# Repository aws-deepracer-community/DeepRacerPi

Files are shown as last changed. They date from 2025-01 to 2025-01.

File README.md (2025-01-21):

# Introducing the DeepRacer Pi: A Budget-Friendly Compute Module Replacement for AWS DeepRacer

The **DeepRacer Pi** is a custom-designed PCB that serves as a cost-effective replacement for the original AWS DeepRacer compute module. With a production and assembly cost of just **$33**, the DeepRacer Pi brings the power of the **Raspberry Pi Compute Module 4 (CM4)** and the upcoming **Compute Module 5 (CM5)** to your DIY racing projects.

PiRacer PCB

## What You Need
To get started with the DeepRacer Pi, you’ll need:
1. **Raspberry Pi CM4 Lite**: 
2. **SD Card**: 
3. **PiCamera V2**:

---

The DeepRacer Pi empowers makers and students to build, modify, and innovate with their AWS DeepRacer cars. it is a small enough package to fit into 1/28th scale car significantly reducing the footprint needed for AWS DeepRacer.

## TODO for DeepRacer Pi Development
1. **Move Camera and unneeded headers**
   - remove the extra header not needed for the servo control
   - move the camera next to the headers to face forward

2. **Implement Battery Monitor**  
   - Add circuitry and software support to monitor battery voltage and health.
   - Display battery status in real-time for improved usability.

3. **Fix USB OTG Support**  
   - Modify USB configuration to enable OTG (On-The-Go) functionality.
   - Ensure compatibility with peripherals and reliable data transfer.
4. **Add Tail light LED**
   - Implement multicolor Tail light indicator
5. **Add Fan header**
   - Enable FAN for additional cooling support
6. **Add UART via serial connector headers**
   - to enable additional debugging

## Setting Up the board

1. **Image SD card with  Ubuntu 22.04**
   - use win+shift+x to enable SSH and Wifi during imaging process
   - Edit /boot/firmware/config.txt
     - Add dtparam=i2c_arm=on
     - Add Start_x=1
     - Add dtoverlay=vc4-fkms-v3d
2. Follow these instructions
   - https://github.com/aws-deepracer-community/deepracer-custom-car

Special Thanks for Lars for all the work he did on the Deepracer-custom-car repo to make this a possibility!

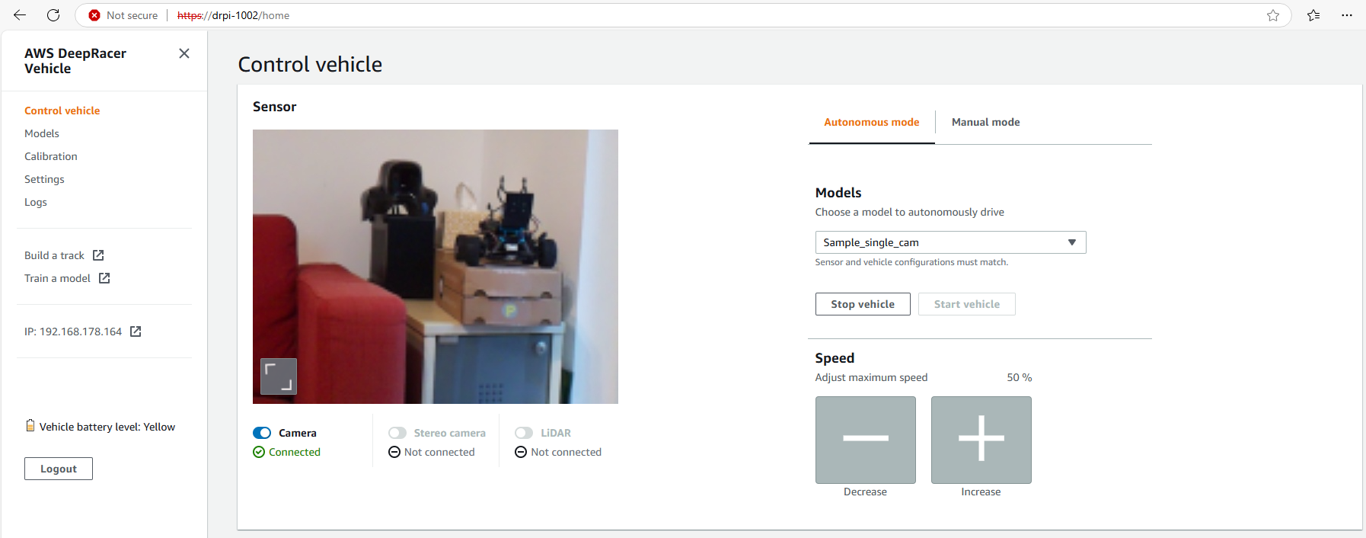
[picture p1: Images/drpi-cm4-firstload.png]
PiRacer PCB


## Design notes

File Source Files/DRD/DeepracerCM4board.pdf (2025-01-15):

Carrier board for CM4

Servo Controller

Power supply: 5V (Pi connector) OR 6V~12V (VIN terminal) - JST-XH 3-pin connection

Servo voltage: 5V

Logic voltage: 3.3V

Driver: PCA9685

Control interface: I2C

Camera connection

SD card Connection

USB Port

USB-C additional power input along with the battery.

Battery gauge

Hirose connector for the CM4 board.

The implementation of the PCA9685 should mimic the waveshare hat for the raspberry pi 4 found here:

https://www.waveshare.com/product/raspberry-pi/hats/motors-relays/servo-driver-hat.htm

1

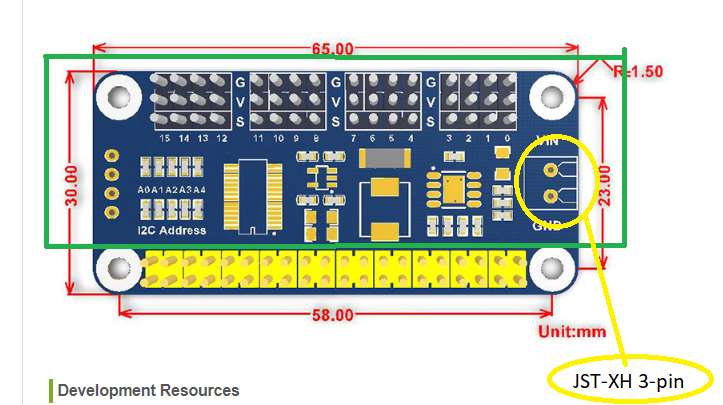
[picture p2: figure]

Data sheet: https://www.waveshare.com/wiki/Servo_Driver_HAT
Schematic: https://files.waveshare.com/upload/a/a2/Servo_Driver_HAT_Schematic_.pdf

I do not want all the connections that exist on the board below. the below board is linked for roughly footprint size I am looking,
Similar to the board size and orientation I am looking for however, I would need mount holes so a little sider is ok. https://www.waveshare.com/product/raspberry-pi/boards-kits/computemodule-4-cat/cm4-nano-c.htm?___SID=U

datasheet: https://www.waveshare.com/wiki/CM4-NANO-C
schematic: https://files.waveshare.com/upload/d/de/CM4-NANO-C-SCH.pdf

2

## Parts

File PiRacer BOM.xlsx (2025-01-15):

Id | Footprint | Quantity | Designators | Designation | Digikey Link
1 | RES_0816_SUS | 2 | R2, R6 | RG1608P-512-B-T5 | https://www.digikey.com/en/products/detail/susumu/RG1608P-512-B-T5/1240605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
2 | MOLEX_1054500101 | 1 | J7 | 1054500101 | https://www.digikey.com/en/products/detail/molex/1054500101/5843890
3 | IND_TAIYO_NR8040_TAY | 1 | L2 | NR8040T3R6N | https://www.digikey.com/en/products/detail/taiyo-yuden/NR8040T3R6N/1739080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
4 | 805 | 1 | R4 | RC0805FR-07115KL | https://www.digikey.com/en/products/detail/yageo/RC0805FR-07115KL/727564
5 | 1206 | 1 | R12 | RC1206FR-0722K1L | https://www.digikey.com/en/products/detail/yageo/RC1206FR-0722K1L/728690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
6 | TSOT-23-5 | 1 | IC1 | RT9742GGJ5 | https://www.digikey.com/en/products/detail/richtek-usa-inc/RT9742GGJ5/5880519
7 | RC0402N_YAG | 6 | R1, R15, R16, R21, R22, R23 | RC0402JR-0710KL | https://www.digikey.com/en/products/detail/yageo/RC0402JR-0710KL/726418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
8 | SO-8EP_DIO | 1 | U5 | AP64501SP-13 | https://www.digikey.com/en/products/detail/diodes-incorporated/AP64501SP-13/10419715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
11 | RESC2012X60N | 1 | R3 | RMCF0805FT15K8 (https://www.digikey.com/en/products/detail/stackpole-electronics-inc/RMCF0805FT15K8/1712710) | https://www.digikey.com/en/products/detail/stackpole-electronics-inc/RMCF0805FT15K8/1712710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
12 | RC0805N_YAG | 1 | C12 | CGA4J2X7R2A104K125AA | https://www.digikey.com/en/products/detail/tdk-corporation/CGA4J2X7R2A104K125AA/2443305
13 | CAPC3225X270N | 3 | C8, C9, C11 | TMK325B7226MMHP | https://www.digikey.com/en/products/detail/taiyo-yuden/TMK325B7226MMHP/10473818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
14 | CAPC1608X90 | 1 | C6 | CC0603KRX7R9BB272 | https://www.digikey.com/en/products/detail/yageo/CC0603KRX7R9BB272/5195216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
16 | CAPC1608X90 | 1 | C4 | 0603B102K500SD | https://www.digikey.com/en/products/detail/nextgen-components/0603B102K500SD/15761330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
17 | CAP_CL31_SAM | 1 | C3 | CL31A106MAHNNNE | https://www.digikey.com/en/products/detail/samsung-electro-mechanics/CL31A106MAHNNNE/3886839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
18 | CONN_61300411121_WRE | 4 | J4, J10, J11, J12 | 61300411121 | https://www.digikey.com/en/products/detail/w%C3%BCrth-elektronik/61300411121/4846827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
19 | SOT361-1_NXP-M | 1 | U2 | PCA9685PW,112 | https://www.digikey.com/en/products/detail/nxp-usa-inc/PCA9685PW-112/2034324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
20 | TSW-104-07-G-D_SAI | 4 | J3, J5, J8, J9 | TSW-104-07-F-D | https://www.digikey.com/en/products/detail/samtec-inc/TSW-104-07-F-D/2685891
21 | CAP_GRM21_2p15X1p4X1p4_MUR | 1 | C21 | GRM21BR71A106KA73L | https://www.digikey.com/en/products/detail/murata-electronics/GRM21BR71A106KA73L/5027600
22 | Raspberry-Pi-4-Compute-Module | 2 | Module1A, Module1B | DF40C-100DS-0.4V | https://www.digikey.com/en/products/detail/hirose-electric-co-ltd/DF40C-100DS-0-4V-51/1969476
23 | JST_B3B-XH-A | 1 | J2 | B3B-XH-A | https://www.digikey.com/en/products/detail/jst-sales-america-inc/B3B-XH-A/1651046
24 | CON15_1X15_DRB_SFW_FCI | 1 | J1 | SFW15R-1STAE1LF | https://www.digikey.com/en/products/detail/amphenol-cs-fci/SFW15R-1STAE1LF/4270877
25 | SDCARD_MOLEX_503398-1892 | 1 | J6 | 5033981892 | https://www.digikey.com/en/products/detail/molex/5033981892/4555393
15 | CAP_CC0805_YAG-L | 1 | C5 | CC0805ZRY5V7BB104 | https://www.digikey.com/en/products/detail/yageo/CC0805ZRY5V7BB104/5884304

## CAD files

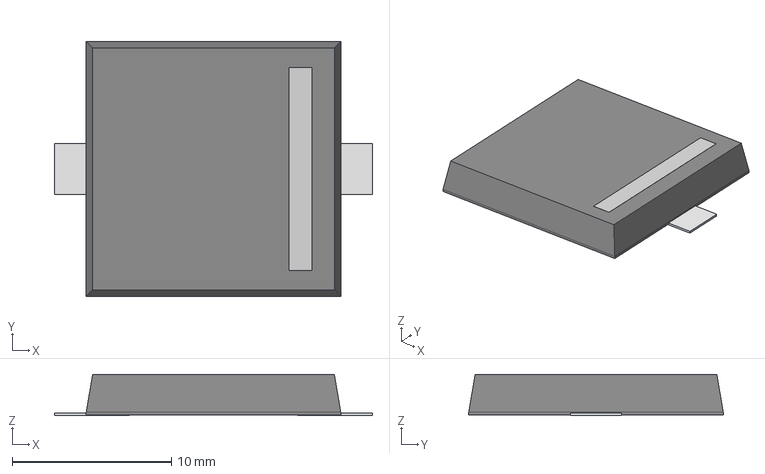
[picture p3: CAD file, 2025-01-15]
Source Files/3Ds/CMT-1603-SMT-TR_CUD.step
20.0 x 16.0 x 2.60 mm

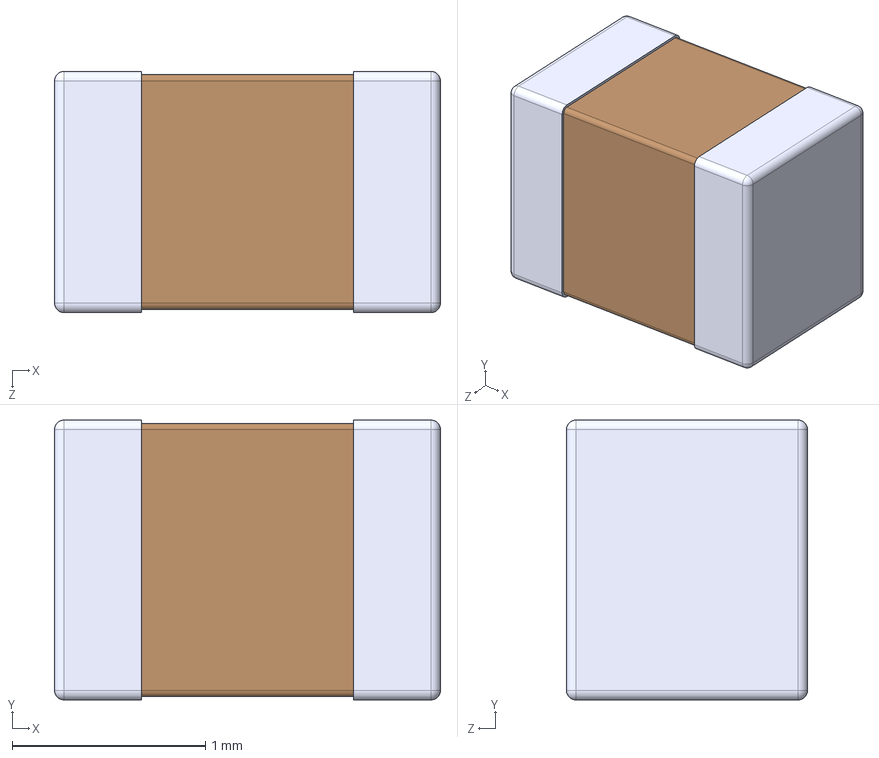
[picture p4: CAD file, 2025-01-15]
Source Files/GRM21BC8YA106KE11L.step
2.00 x 1.45 x 1.25 mm

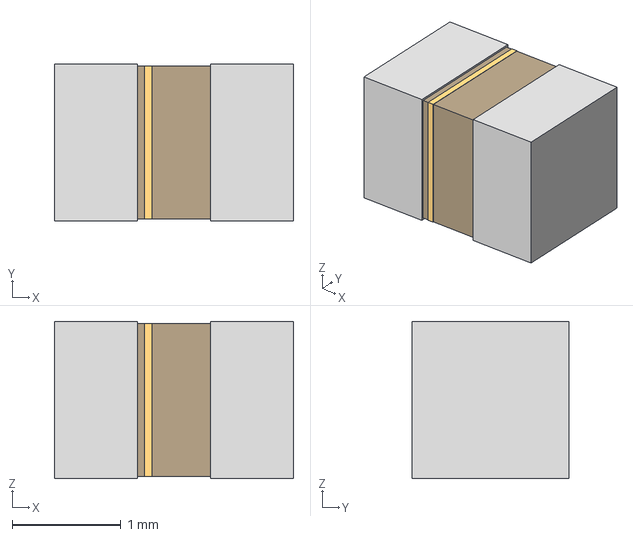
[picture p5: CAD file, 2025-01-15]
Source Files/3Ds/CAP_CC0805_YAG.step
2.20 x 1.45 x 1.45 mm

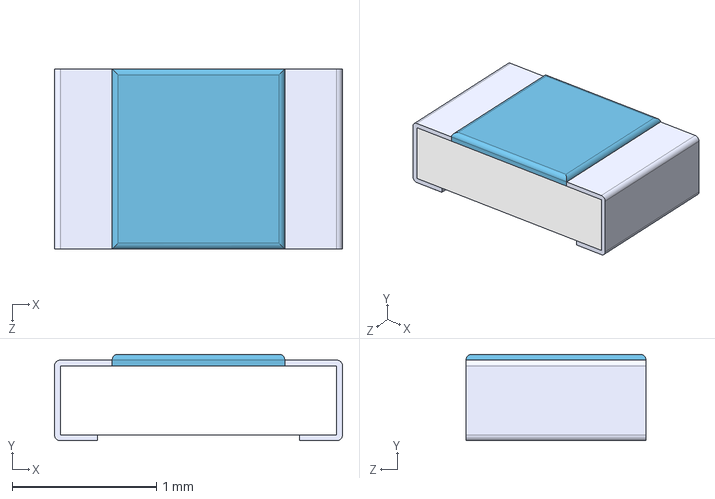
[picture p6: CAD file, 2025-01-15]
Source Files/3Ds/RK73H2ATTD1582F.step
2.00 x 0.6 x 1.25 mm

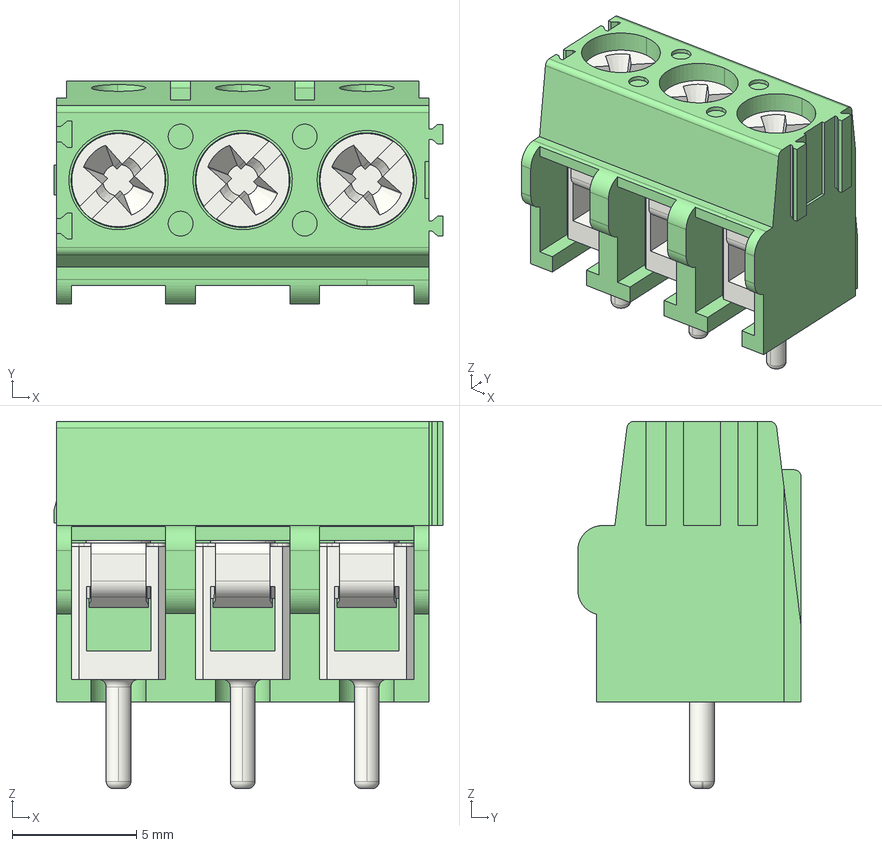
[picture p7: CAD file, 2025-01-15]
Source Files/3Ds/pxc_1935174_05_01_PT-1-5-3-5-0-H_3D.stp
15.7 x 9.00 x 14.8 mm

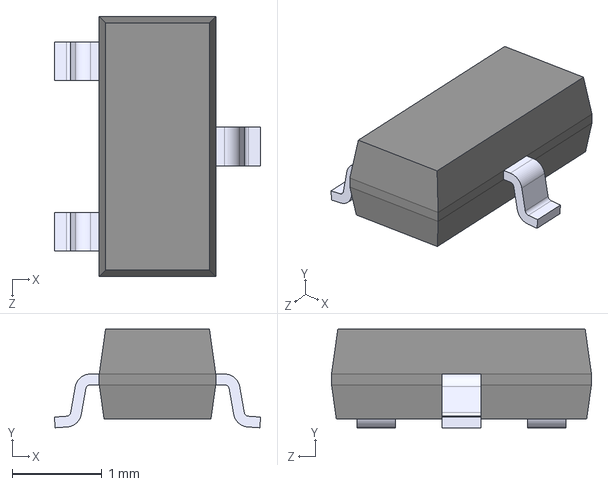
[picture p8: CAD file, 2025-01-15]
Source Files/3Ds/BZX84-C12_215.step
2.30 x 1.10 x 2.90 mm

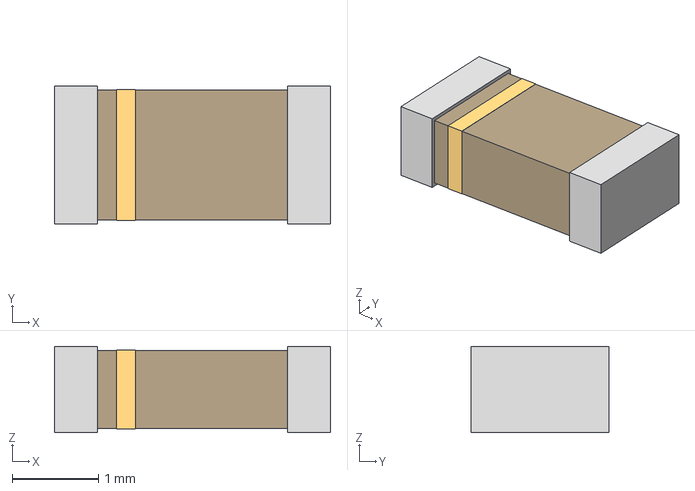
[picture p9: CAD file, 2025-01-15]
Source Files/3Ds/CAP_CL31_SAM.step
3.20 x 1.60 x 1.00 mm

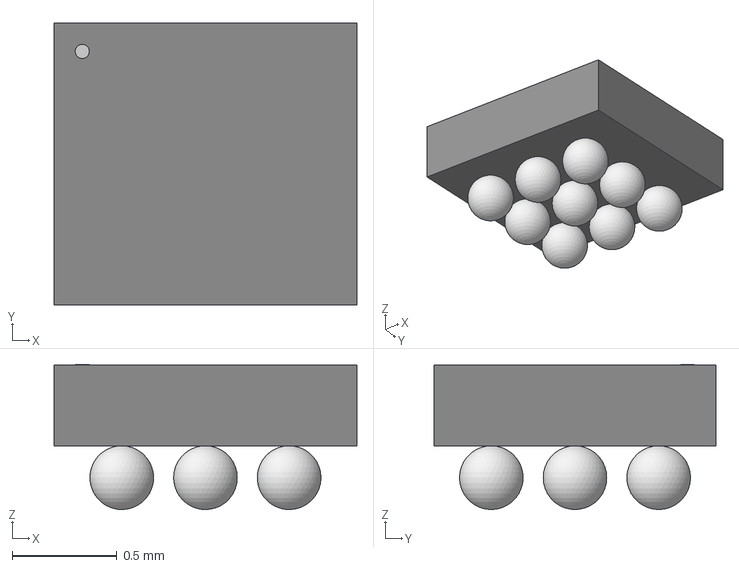
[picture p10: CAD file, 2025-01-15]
Source Files/3Ds/21-0896B_9_MXM.step
1.45 x 1.35 x 0.693 mm

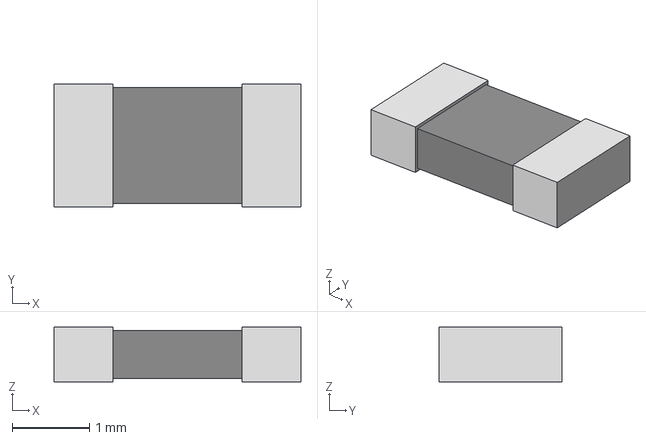
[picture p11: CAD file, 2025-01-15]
Source Files/3Ds/RC1206N_YAG.step
3.20 x 1.60 x 0.711 mm

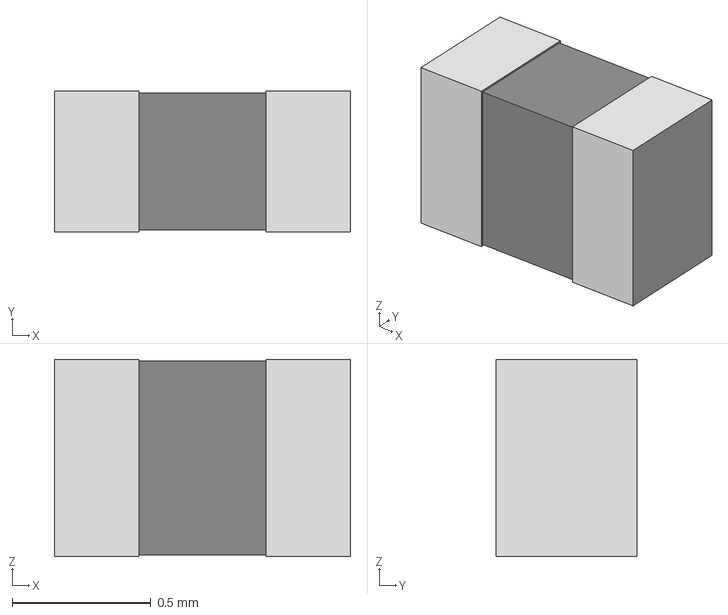
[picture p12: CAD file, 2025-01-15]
Source Files/3Ds/RC0402N_YAG.step
1.07 x 0.508 x 0.711 mm

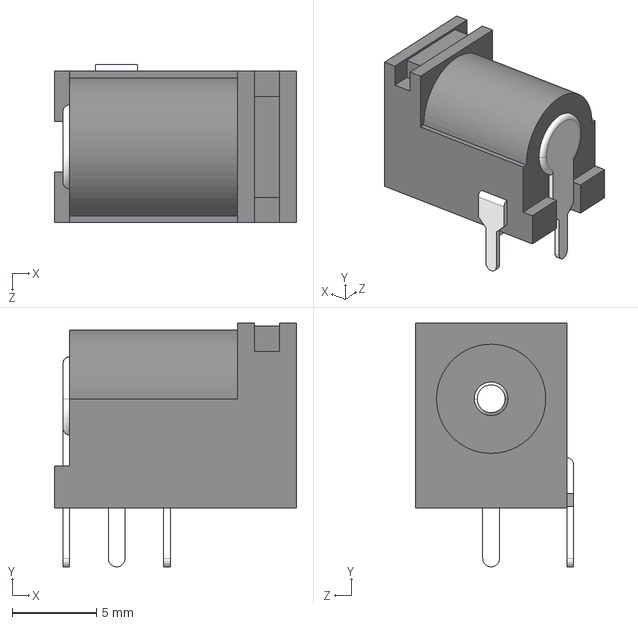
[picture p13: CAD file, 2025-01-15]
Source Files/3Ds/PJ-102AH.step
14.4 x 14.5 x 9.40 mm

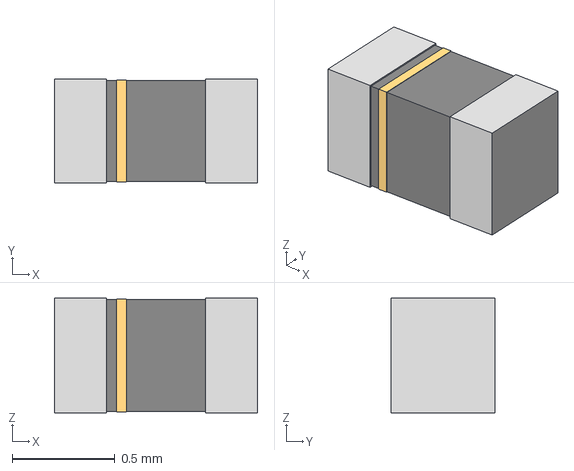
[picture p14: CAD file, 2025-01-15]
Source Files/3Ds/G-155_MUR.step
0.99 x 0.508 x 0.559 mm

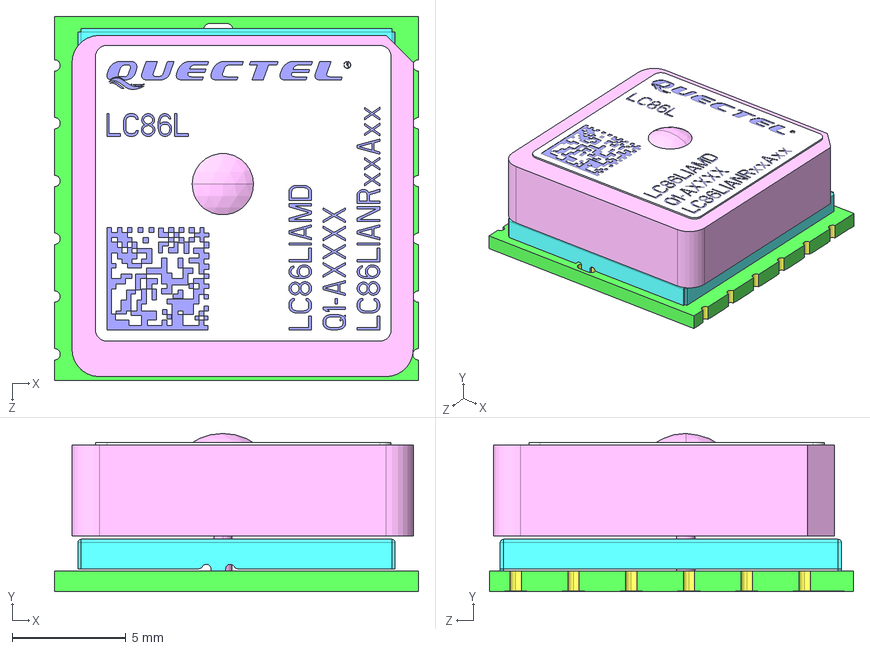
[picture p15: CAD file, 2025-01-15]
Source Files/3Ds/LC86LICMD.STEP
16.0 x 6.95 x 16.0 mm

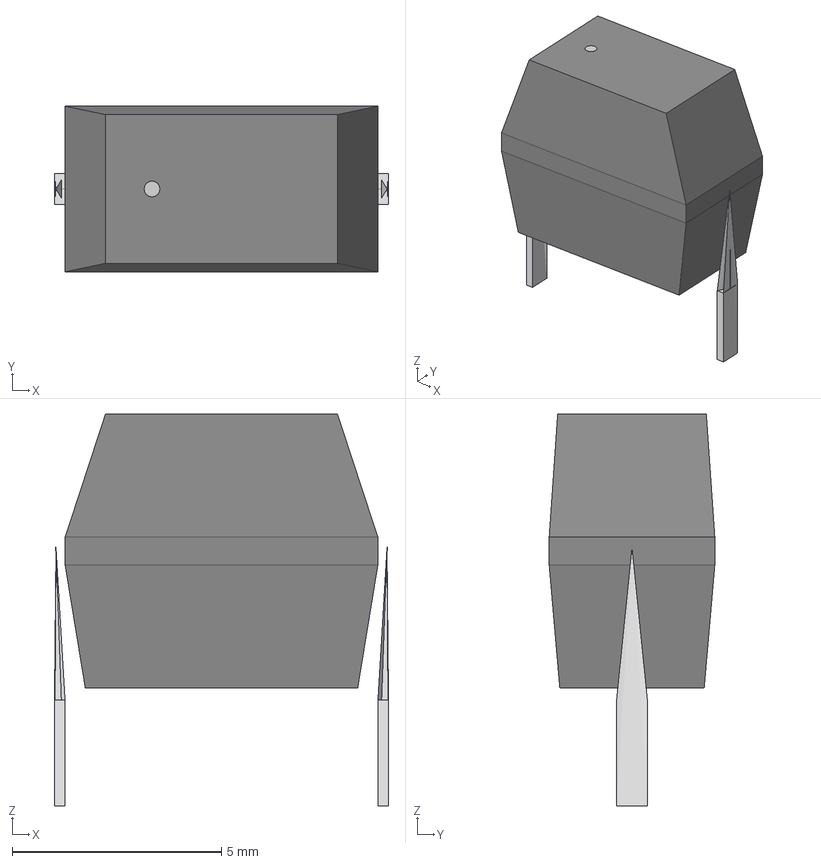
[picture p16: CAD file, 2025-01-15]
Source Files/3Ds/SW_DS01-254-L-01BE_CUD.step
7.99 x 3.96 x 9.38 mm

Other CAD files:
Source Files/3Ds/CC0603KRX7R9BB272.step
Source Files/3Ds/DC-001-A-2.1mm-R.STEP
Source Files/3Ds/RES_R0805_ROM.step
Source Files/3Ds/MAX485CSA_T.step
Source Files/3Ds/0805_AVX.step
Source Files/3Ds/1-2199230-5.step
Source Files/3Ds/104031-0811.step
Source Files/3Ds/1040310811.stp
Source Files/3Ds/1054500101.step
Source Files/3Ds/1757242.step
Source Files/3Ds/1759020.step
Source Files/3Ds/20021321-00006C4LF.step
Source Files/3Ds/20021321-00006C4LF.stp
Source Files/3Ds/20021321-1006xxlfc.stp
Source Files/3Ds/282834-3.step
Source Files/3Ds/35WR10KLFTR.step
Source Files/3Ds/5033981892.stp
Source Files/3Ds/503960-0695.step
Source Files/3Ds/530480210.stp
Source Files/3Ds/APC-817xx-SL_AMB.step
Source Files/3Ds/B3B-XH-A.step
Source Files/3Ds/CAP_2012_TDK.step
Source Files/3Ds/CAP_3216_TDK.step
Source Files/3Ds/CAP_GRM155R62A104KE14D_MUR.step
Source Files/3Ds/CC0603JRX7R8BB103.step
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

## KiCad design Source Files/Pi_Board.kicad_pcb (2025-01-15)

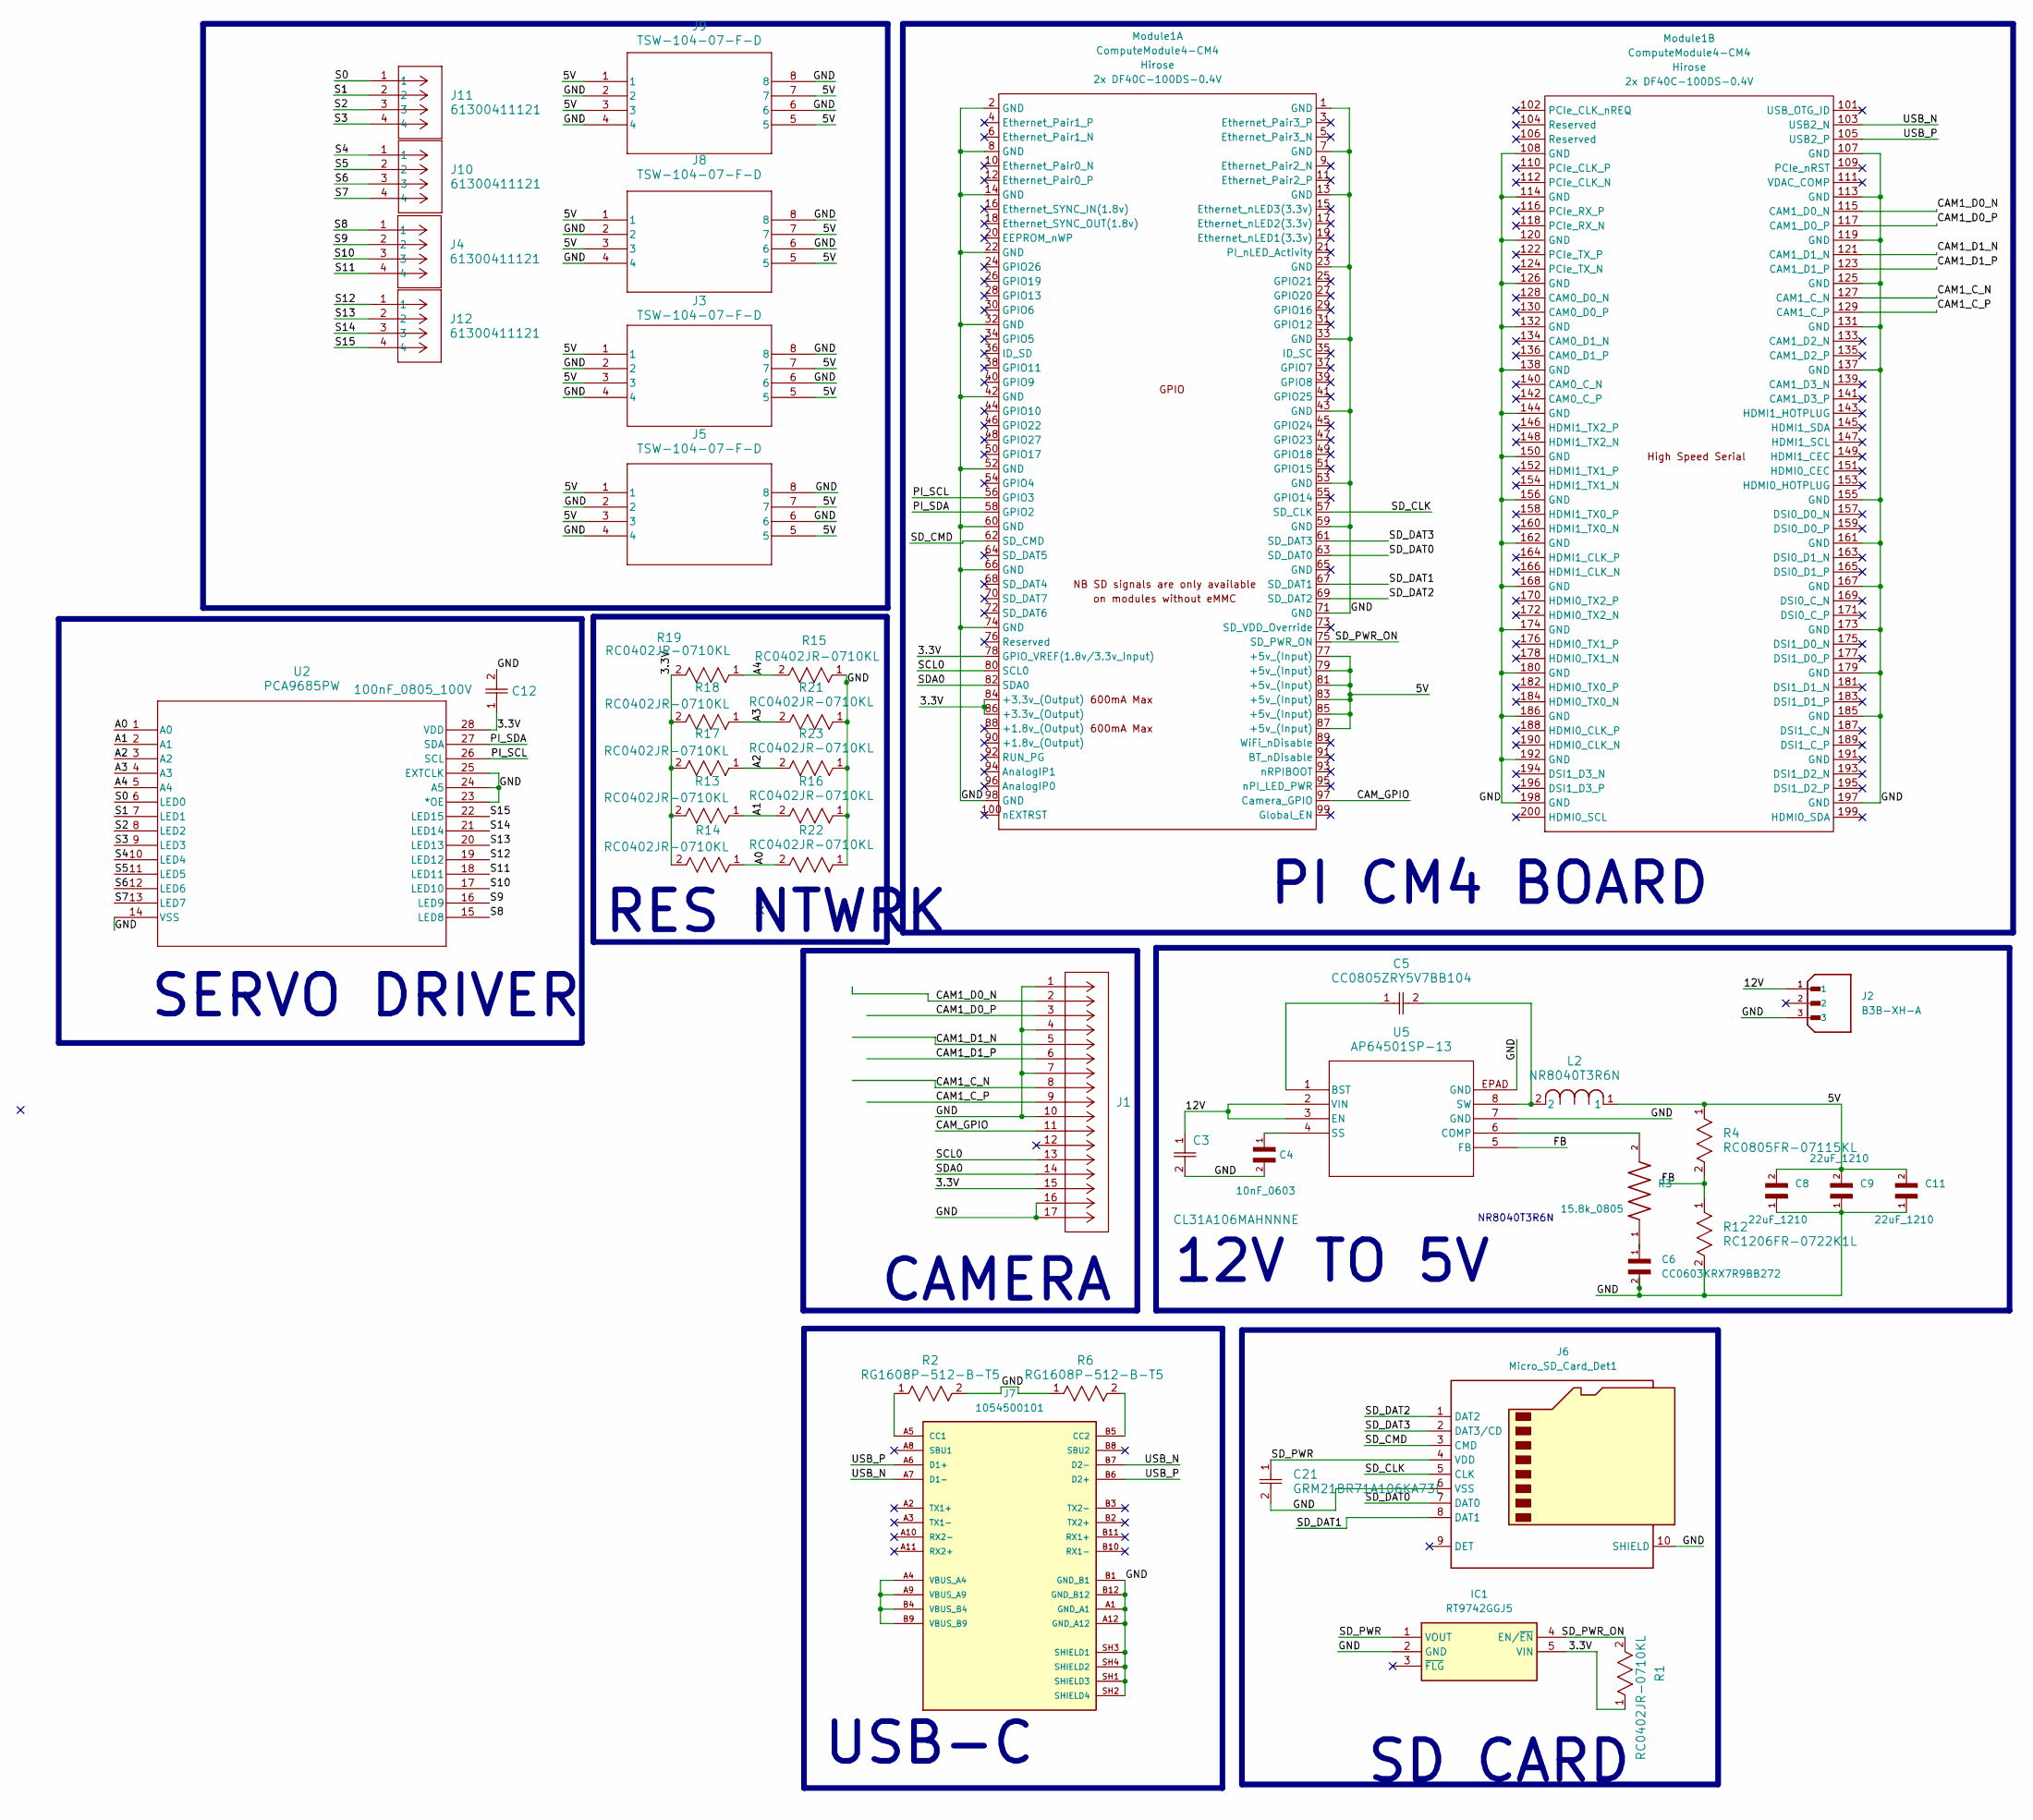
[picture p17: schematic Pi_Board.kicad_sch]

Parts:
C3: CL31A106MAHNNNE; CAP_CL31_SAM; Part Number CL31A106MAHNNNE
C4: 10nF_0603; CAPC1608X90
C5: CC0805ZRY5V7BB104; CAP_CC0805_YAG-L
C6: CC0603KRX7R9BB272; CAPC1608X90; Part Number CC0603KRX7R9BB272
C8, C9, C11: 22uF_1210; CAPC3225X270N
C12: 100nF_0805_100V; RC0805N_YAG
C21: GRM21BR71A106KA73L; CAP_GRM21_2p15X1p4X1p4_MUR; Part Number GRM21BR71A106KA73L
IC1: RT9742GGJ5; SOT94P280X100-5N; Mouser Part Number 835-RT9742GGJ5
J1: 15 Pin; CON15_1X15_DRB_SFW_FCI; Part Number SFW15R-2STE1LF
J2: B3B-XH-A; JST_B3B-XH-A; PARTREV 7/4/21
J3, J5, J8, J9: TSW-104-07-F-D; TSW-104-07-G-D_SAI
J4, J10, J11, J12: 61300411121; CONN_61300411121_WRE
J6: Micro_SD_Card_Det1; SDCARD_MOLEX_503398-1892
J7: 1054500101; MOLEX_1054500101; PARTREV A7
L2: NR8040T3R6N; IND_TAIYO_NR8040_TAY; Part Number NR8040T3R6N
Module1: ComputeModule4-CM4; Raspberry-Pi-4-Compute-Module
R1, R13, R14, R15, R16, R17, R18, R19, R21, R22, R23: RC0402JR-0710KL; RC0402N_YAG
R2, R6: RG1608P-512-B-T5; RES_0816_SUS
R3: 15.8k_0805; RESC2012X60N
R4: RC0805FR-07115KL; RC0805N_YAG-M
R12: RC1206FR-0722K1L; RC1206N_YAG-L
U2: PCA9685PW; SOT361-1_NXP-M
U5: AP64501SP-13; SO-8EP_DIO

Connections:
/3.3V: C12.1, IC1.5 (VIN), J1.15, Module1.78 (GPIO_VREF(1.8v/3.3v_Input)), Module1.84 (+3.3v_(Output)), Module1.86 (+3.3v_(Output)), R1.1, R13.2, R14.2, R17.2, R18.2, R19.2, U2.28 (VDD)
/5V: C8.2, C9.2, C11.2, J3.1, J3.3, J3.5, J3.7, J5.1, J5.3, J5.5, J5.7, J8.1, J8.3, J8.5, J8.7, J9.1, J9.3, J9.5, J9.7, L2.1, Module1.77 (+5v_(Input)), Module1.79 (+5v_(Input)), Module1.81 (+5v_(Input)), Module1.83 (+5v_(Input)), Module1.85 (+5v_(Input)), Module1.87 (+5v_(Input)), R4.1
/12V: C3.1, J2.1, U5.2 (VIN), U5.3 (EN)
/A0: R14.1, R22.2, U2.1 (A0)
/A1: R13.1, R16.2, U2.2 (A1)
/A2: R17.1, R23.2, U2.3 (A2)
/A3: R18.1, R21.2, U2.4 (A3)
/A4: R15.2, R19.1, U2.5 (A4)
/CAM1_C_N: J1.8, Module1.127 (CAM1_C_N)
/CAM1_C_P: J1.9, Module1.129 (CAM1_C_P)
/CAM1_D0_N: J1.2, Module1.115 (CAM1_D0_N)
/CAM1_D0_P: J1.3, Module1.117 (CAM1_D0_P)
/CAM1_D1_N: J1.5, Module1.121 (CAM1_D1_N)
/CAM1_D1_P: J1.6, Module1.123 (CAM1_D1_P)
/CAM_GPIO: J1.11, Module1.97 (Camera_GPIO)
/FB: R4.2, R12.1, U5.5 (FB)
/GND: C3.2, C4.2, C6.2, C8.1, C9.1, C11.1, C12.2, C21.2, IC1.2 (GND), J1.1, J1.4, J1.7, J1.10, J1.16, J1.17, J2.3, J3.2, J3.4, J3.6, J3.8, J5.2, J5.4, J5.6, J5.8, J6.6 (VSS), J6.10 (SHIELD), J7.A1 (GND_A1), J7.A12 (GND_A12), J7.B1 (GND_B1), J7.B12 (GND_B12), J7.SH1 (SHIELD3), J7.SH2 (SHIELD4), J7.SH3 (SHIELD1), J7.SH4 (SHIELD2), J8.2, J8.4, J8.6, J8.8, J9.2, J9.4, J9.6, J9.8, Module1.1 (GND), Module1.2 (GND), Module1.7 (GND), Module1.8 (GND), Module1.13 (GND), Module1.14 (GND), Module1.22 (GND), Module1.23 (GND), Module1.32 (GND), Module1.33 (GND), Module1.42 (GND), Module1.43 (GND), Module1.52 (GND), Module1.53 (GND), Module1.59 (GND), Module1.60 (GND), Module1.66 (GND), Module1.71 (GND), Module1.74 (GND), Module1.98 (GND), Module1.107 (GND), Module1.108 (GND), Module1.113 (GND), Module1.114 (GND), Module1.119 (GND), Module1.120 (GND), Module1.125 (GND), Module1.126 (GND), Module1.131 (GND), Module1.132 (GND), Module1.137 (GND), Module1.138 (GND), Module1.144 (GND), Module1.150 (GND), Module1.155 (GND), Module1.156 (GND), Module1.161 (GND), Module1.162 (GND), Module1.167 (GND), Module1.168 (GND), Module1.173 (GND), Module1.174 (GND), Module1.179 (GND), Module1.180 (GND), Module1.185 (GND), Module1.186 (GND), Module1.192 (GND), Module1.197 (GND), Module1.198 (GND), R2.2, R6.1, R12.2, R15.1, R16.1, R21.1, R22.1, R23.1, U2.14 (VSS), U2.23 (*OE), U2.24 (A5), U2.25 (EXTCLK), U5.7 (GND), U5.EPAD (GND)
/PI_SCL: Module1.56 (GPIO3), U2.26 (SCL)
/PI_SDA: Module1.58 (GPIO2), U2.27 (SDA)
/S0: J11.1, U2.6 (LED0)
/S1: J11.2, U2.7 (LED1)
/S2: J11.3, U2.8 (LED2)
/S3: J11.4, U2.9 (LED3)
/S4: J10.1, U2.10 (LED4)
/S5: J10.2, U2.11 (LED5)
/S6: J10.3, U2.12 (LED6)
/S7: J10.4, U2.13 (LED7)
/S8: J4.1, U2.15 (LED8)
/S9: J4.2, U2.16 (LED9)
/S10: J4.3, U2.17 (LED10)
/S11: J4.4, U2.18 (LED11)
/S12: J12.1, U2.19 (LED12)
/S13: J12.2, U2.20 (LED13)
/S14: J12.3, U2.21 (LED14)
/S15: J12.4, U2.22 (LED15)
/SCL0: J1.13, Module1.80 (SCL0)
/SDA0: J1.14, Module1.82 (SDA0)
/SD_CLK: J6.5 (CLK), Module1.57 (SD_CLK)
/SD_CMD: J6.3 (CMD), Module1.62 (SD_CMD)
/SD_DAT0: J6.7 (DAT0), Module1.63 (SD_DAT0)
/SD_DAT1: J6.8 (DAT1), Module1.67 (SD_DAT1)
/SD_DAT2: J6.1 (DAT2), Module1.69 (SD_DAT2)
/SD_DAT3: J6.2 (DAT3/CD), Module1.61 (SD_DAT3)
/SD_PWR: C21.1, IC1.1 (VOUT), J6.4 (VDD)
/SD_PWR_ON: IC1.4 (EN/~EN), Module1.75 (SD_PWR_ON), R1.2
/USB_N: J7.A7 (D1-), J7.B7 (D2-), Module1.103 (USB2_N)
/USB_P: J7.A6 (D1+), J7.B6 (D2+), Module1.105 (USB2_P)
unnamed: C6.1, R3.1
unnamed: J7.A5 (CC1), R2.1
unnamed: J7.B5 (CC2), R6.2
unnamed: J7.A4 (VBUS_A4), J7.A9 (VBUS_A9), J7.B4 (VBUS_B4), J7.B9 (VBUS_B9)
unnamed: C5.1, U5.1 (BST)
unnamed: R3.2, U5.6 (COMP)
unnamed: C4.1, U5.4 (SS)
unnamed: C5.2, L2.2, U5.8 (SW)

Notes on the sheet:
SD CARD
NR8040T3R6N
SERVO DRIVER
PI CM4 BOARD
12V TO 5V
CAMERA
USB-C
RES NTWRK

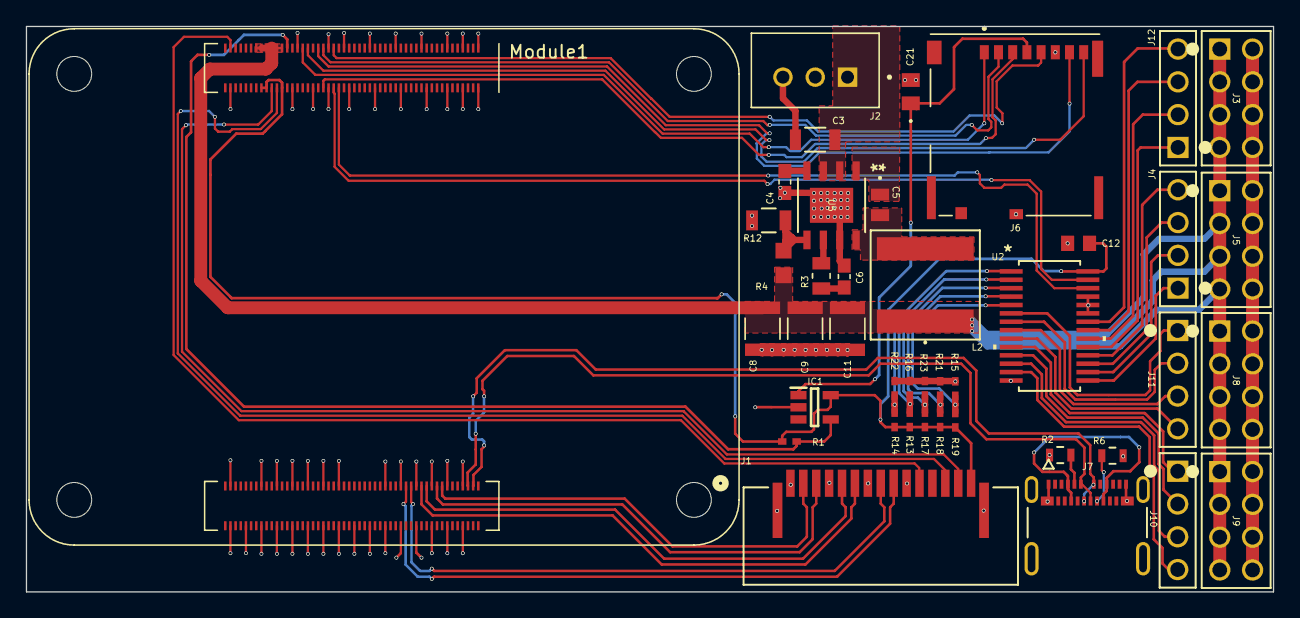
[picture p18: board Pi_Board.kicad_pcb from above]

Board: 2 copper layers, 96.6 x 43.8 mm, 42 parts (0 on the bottom side), 55 nets.

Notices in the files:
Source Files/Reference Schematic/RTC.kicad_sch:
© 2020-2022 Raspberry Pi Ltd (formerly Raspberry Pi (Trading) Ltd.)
